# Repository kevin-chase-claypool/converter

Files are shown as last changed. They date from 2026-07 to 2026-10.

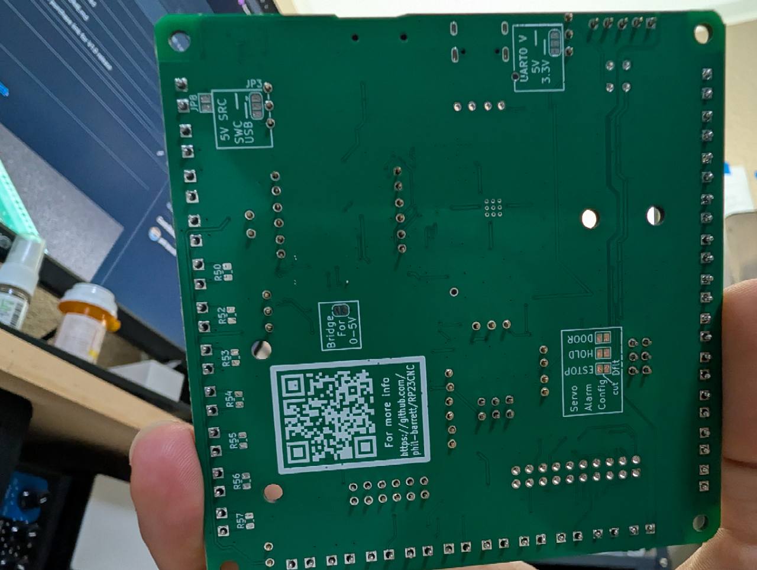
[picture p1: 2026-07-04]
docs/report/lab-notes/assets/2026-06-09-rp23u5xbb-v1.01-back.jpg

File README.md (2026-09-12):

# Theta Pen Plotter — System Integration Project

A polar (XY + rotating-bed) pen-plotting system. SVG artwork is converted on a
host PC into G-code for a machine whose **bed rotates under an XY gantry**, with a
force-controlled pen. This repository is split into independent components so each
can be edited and iterated on its own.

## Components

| Folder | What it is | Language / target |
|---|---|---|
| [`software/`](software/) | Host desktop app: SVG → G-code converter with a live Qt/OpenGL preview | Python 3 + PySide6 |
| [`firmware/`](firmware/) | Machine controller (motion via grblHAL) + the pen-pressure control system | grblHAL on RP23CNC; SparkFun Pro Micro RP2350 on the toolhead |
| [`docs/`](docs/) | Design/handoff notes and the System Integration in Robotics report | Markdown |
| [`samples/`](samples/) | Example SVG inputs and generated G-code outputs | assets |

New contributors and AI sessions should begin with
[`docs/START_HERE.md`](docs/START_HERE.md). It links the hardware inventory,
engineering log, master wiring table, architecture, interface contracts,
roadmap, test plan, and the categorized
[`change index`](docs/changes/INDEX.md).

For architecture, dependency, impact, or cross-subsystem investigations using
the local Ontoly graph, begin with the reusable
[`ONTOLY_PROMPT.md`](ONTOLY_PROMPT.md). It pairs graph evidence with the
authoritative interface, wiring, and commissioning records.

For a quick status view, open
[`project_management_overview.html`](project_management_overview.html) from the
repository root. It summarizes the active phase, current blockers, next work,
and links back to the controlling project documents.

## Run the converter

Double-click **`converter.bat`** (launches the Qt/OpenGL app and logs to
`software/qt_debug.log`), or:

```powershell
python software\qt_svg_to_gcode.pyw
```

See [`software/README.md`](software/README.md) for full usage and settings.

## System overview

```
   SVG  ──►  software/ (host)  ──►  .gcode  ──►  ioSender  ──►  RP23CNC + grblHAL  ──►  machine
                                                              │
                                                              └─ M3/M5 tool output ──►  pen-pressure MCU
```

- The host converter maps SVG artwork (bed-local coordinates) into machine
  `X/Y/A` moves for the rotating bed, and emits pen up/down as `M3`/`M5`.
- ioSender is the operator-facing G-code sender: it streams the saved G-code to
  RP23CNC over USB or Ethernet and provides the console, settings, jog, and
  status interface during setup and operation.
- grblHAL on RP23CNC parses the streamed G-code and drives the X/Y/A steppers.
- The pen-pressure system is an independent closed loop that treats the grblHAL
  `M3`/`M5` spindle/tool output state as a **mode override** (engage / lift) and
  otherwise holds a target contact force.

Use [`docs/README.md`](docs/README.md) to find the current architecture,
interfaces, tests, and open work. [`docs/HANDOFF.md`](docs/HANDOFF.md) retains
converter history and technical tradeoffs.

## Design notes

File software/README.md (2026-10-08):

# Host software — SVG → G-code converter

Converts `.svg` artwork into `.gcode` for the XY + rotating-bed (theta) machine,
with a live preview of the simulated machine motion.

- `qt_svg_to_gcode.pyw` — the primary app: PySide6 + OpenGL preview, playback,
  and all conversion settings in one window.
- `converter_core/` — the conversion engine split by responsibility:
  settings, SVG geometry, kinematics/planning, and G-code/preview move emission.
- `svg_to_gcode.pyw` — a compatibility shim for older imports and simple
  `input.svg output.gcode` command-line conversion.
- `qt_kaleidoscope.pyw` — the sibling app: imports an SVG, PNG or JPG, mirrors
  it into N kaleidoscope divisions, and saves the same G-code contract.
  Launched by `..\kaleidoscope.bat`; it reuses `converter_core/` unchanged.
  Its second tab, **Maps**, embeds a local copy of `piebro/plotting-maps` for
  turning OpenStreetMap exports into plotter SVGs.

## Run

```powershell
python qt_svg_to_gcode.pyw
```

or double-click `..\converter.bat` from the repo root. Runtime errors are written
to `qt_debug.log` in this folder.

Requires `PySide6` (`pip install PySide6`). The kaleidoscope's **Maps** tab
also needs Qt WebEngine, which ships in the full `PySide6` wheel
(`PySide6-Addons`); without it the tab reports the missing module instead of
failing the app.

The first two lines of `qt_debug.log` (and of the window's log pane) name the
converter core and the active A-axis guard, e.g.
`[A guard: park above 10 deg/segment, 20000 motor deg/min, travel rotations fed]`.
A window opened before a core change keeps the old planner in memory, so that
line is how a stale instance is told from a current one.

To check a *saved* file instead of the running app:

```powershell
python ..\tools\check_gcode_motion.py ..\samples\gcode\my-job.gcode --strict
```

It reports the largest bed rotation inside one drawing move, the largest A rate
demanded, whether any pen-up move carries rotation as a bare `G0` rapid, and the
worst commanded bed-path bow with its radius - measured from the file, so it
answers "did this program get the guard?" without guessing.

Two repeatability programs exist for measuring the machine itself, both safe to
Cycle Start with the pen loaded:

- `..\samples\gcode\a-repeatability-test.gcode` - the bed: a radial tick, two
  bed revolutions out and two back with the pen down, the tick again, at
  r = 100 mm and r = 160 mm. Ticks on top of each other means the bed returned.
- `..\samples\gcode\y-repeatability-test.gcode` - the heavy gantry axis: a tick
  across the axis, five runs out and back at 3000 / 6000 / 12000 / 20000 mm/min
  with the pen up, the tick again per rung. The top rung is what a `G0` pen-up
  travel actually runs at, because grblHAL ignores the `F` word on a rapid.
  Regenerate either with the matching tool in `..\tools\`
  (`make_a_repeatability_test.py`, `make_xy_repeatability_test.py --axis X`).

## Generator tabs

The window has the standard **File / Tools / View / Help** menu bar. **File**
opens the artwork (Ctrl+O), sets the G-code destination (Ctrl+Shift+S), saves
G-code (Ctrl+S), and exits. **Tools** is the tool selector: **All Tools**
(Ctrl+T) opens the card dashboard (Core, Line art, 3D, Patterns, Text &
layout), **Convert** is Ctrl+1, and the other tools follow in menu order with
Ctrl+2...Ctrl+0. **View** toggles the machine reach guide, pen-down path, and
log, and controls preview zoom. The preview panel also has a **Red motion
lines** checkbox next to Fill bed / Fit inside that toggles the same pen-down
overlay without leaving the preview (it stays in sync with the sidebar
checkbox and the View menu), plus an **Ink simulation (multiply)** checkbox
for CMYK previews: the ink layers multiply over the paper white in plot
order, like translucent pens, so the preview shows the finished overprint
instead of painting each layer opaquely. Simulation strokes draw at the real
pen width, and a stroke thinner than a screen pixel fades toward white by the
fraction of a pixel it covers, so the fit-to-window view keeps the density
the paper will get (zoom in for full-strength strokes). Mixing only happens
where strokes overlap: keep the effective pitch (Dot pitch x Artwork scale,
then the tone-adaptive factor of 1-3x) at or below the pen width for full
coverage. An **Ink profile...** button loads
the `*-profile.json` written by `tools\cmyk_calibrate.py`, so the simulation
multiplies your pens' measured transmittances instead of the display ink
colours. **Help** has the shortcut list
(F1) and About.
The status bar shows the current artwork and G-code paths. Tools are
contributed by `software/generator_tabs/*_tab.py` modules and discovered at
startup, one page per tool; a broken tool is reported in the log instead of
stopping the app.

Import, **Preview / Cancel / Save G-code**, and the OpenGL preview panel are
static window furniture: they stay visible on every tab. Pressing **Preview**
builds the active tab - Convert previews the Artwork row's file, while Flow
Field, Line Draw, and 3D Wireframe build their own SVG from their controls -
and that result runs through the same converter pipeline into the shared
preview panel. **Save G-code** exports the active tab's result. Switching tabs
never rebuilds anything; it marks the visible preview as belonging to another
tab until Preview is pressed again. Multi-layer tools (CMYK) keep that static
Preview for the overlaid view; after a successful preview the four per-ink
programs plan in the background and **Save 4 G-code files** writes them
through one save dialog owned by the window.

Tool authors: the contract and the host entry points are documented in
[`generator_tabs/README.md`](generator_tabs/README.md). Ported or vendored
third-party code keeps its license and attribution in a sibling
`<name>_NOTICE.md`.

Current tools:

**Photo-based** (need an image from File > Open Artwork):

- **Line Draw** - raster image to edge-traced contours plus luminance hatch.
  Controls: artwork (from the static Artwork row), invert, mode
  (contours / hatch / both), edge
  threshold, hatch spacing, hatch light/mid/dark thresholds (upstream
  linedraw levels 144/64/16), sketch jitter, minimum length, simplify,
  resolution, line width, seed, page size, margin, artwork scale.
- **CMYK** - RGB to CMYK separation with gray-component replacement, screened
  as one layer per ink pen. Controls: artwork (from the static Artwork row),
  an **Auto (photo)** button that analyzes the image and sets auto levels,
  brightness, contrast, saturation, GCR, a starting gamma and the dot pitch
  (tone
  controls come from a detail search over the real curve chain: maximum mid
  tone-weighted gradient with a clipping penalty, so structure stays
  legible instead of crushed or blown, and the search also holds the print's
  mean tone on the photo's, clamped to the 0.30-0.75 window a plot can
  actually hold, so portraits are not lifted a stop too light; it also
  renders the rectilinear screen (Pen width and Dot pitch x Artwork scale)
  before choosing, so a row pitch at the pen width - which inks only about a
  fifth of a light tone - gets a darker chain instead of a washed-out plot,
  while a screen finer than the pen gets a lighter one; saturation
  and GCR come from the
  image's colourful quartile, so a vivid subject over neutral ground keeps
  its chroma; the pitch is set to one pen width at the current artwork scale,
  the same as **Match pen**),
  auto levels (default on: stretch the image's 1st-99th luminance percentiles
  so low-key photos use the full tonal range), saturation, contrast,
  brightness, ink gamma, black (GCR), resolution, per-ink weights, screen style
  (halftone dots / stipple dots / line screen / crosshatch levels / wave
  screen / interference (gyroid) / single line (TSP) / topographic contours /
  rectilinear fill),
  dot pitch (with a **Match pen** button that sets it to one pen width at
  the current artwork scale), dot size, solid dots (spiral-filled so each
  mark reads as a dot, not a ring), hatch levels, overdraw, pen width, max
  marks per ink, seed, preview and write checkboxes per layer, page size,
  margin, artwork scale, and registration corner crosses (all four inks
  draw the same four margin crosses so pass alignment can be checked).
  Resolution keeps the source image's longest side up to that many pixels
  and never upsamples, so it accepts high-resolution sources (the control is
  effectively uncapped; memory grows with the source size you keep).
  Shipped defaults are the owner's tuned rectilinear set: auto levels on,
  rectilinear fill at 0.10 mm pitch (its light-tone stretch opens the pitch
  up to 7x, so highlights and mid tones keep paper while dark tones fuse
  solid, and the pitch follows the tone the row actually inks and eases
  between rows so it does not step where the subject meets the background),
  saturation 115 %, contrast 285 % (the soft S-curve keeps
  steepening up to 300 % instead of clipping), brightness 170 %
  (shadow-weighted lift), ink gamma 1.40 (about a third less ink in the mid
  tones), black (GCR)
  95 %, hatch levels 8, artwork scale 280 %, dot size 100 % with solid dots
  off (both only affect the dot screens), 40000 marks per ink, 10000 px
  resolution, C/M/Y/K weights 100/100/100/100 %. The preview checkboxes decide which inks the shared OpenGL preview
  draws, and they apply instantly: every layer stays loaded, so toggling a
  checkbox never re-screens or re-plans. For CMYK previews the preview data
  area also reports the per-ink M3 (pen-down) counts as
  `C: n M: n Y: n K: n`, counted from the planned program.
  Pressing Preview also plans each checked ink's own program in the
  background through the same pipeline as Convert - that planning is exactly
  where the r-theta solver picks x_theta or y_theta per segment, and the tab
  reports each file's split and calibrated time when it finishes.
  **Save 4 G-code files** writes
  `<name>-cyan.gcode`, `-magenta`, `-yellow` and `-black` from one base name.
  The r-theta axis-cost solver and the M3/M5 pen contract are inherited
  unchanged, so each ink is as cost-efficient as a normal Convert program.
  Line, wave, gyroid, TSP and contour styles are the fast continuous-mark
  alternatives to dot styles: they draw far fewer pen-lift cycles, while the
  overdraw control darkens any style by redrawing each mark up to three times
  with a sub-pen offset.
  While the CMYK page is active the shared OpenGL preview draws each visible
  ink in its own colour - not yet drawn marks in a pale tint, the drawn path in
  full ink - so the four layers can be judged overlaid the way they will mesh
  on paper. The red machine-motion overlay and every other tool keep their
  existing single-colour preview.
  **Test sheet** (Calibration group) replaces Preview and Save with a
  calibration page instead of the artwork: per-ink coverage and overdraw
  ladders, a dot-size, line-pitch, or hatch-level ladder, a GCR ramp,
  dense full-tone mixes (pairs, triple, and the C+M+Y+K quad) and single-ink
  spots at the same tight spacing, blank paper, and four corner fiducials;
  the only printed text is a two-line identification header
  (page, margin, screen), because the cell values live in the manifest. The
  **Sheet screen** box defaults to matching your Screen style (line screen
  and crosshatch included), so the ladders calibrate the marks you actually
  print; line sheets draw continuous strokes and need far fewer pen cycles
  than dot screens. Save writes `<name>-calibration-*.gcode` plus
  `<name>-calibration.json`; plot the four files in C, M, Y, K order, scan
  the sheet flat, and run
  `python tools\cmyk_calibrate.py scan.png --manifest <name>-calibration.json`
  to report paper-relative ink transmittances and a multiply-model check for a
  print-matching preview. Ladder cells print raw tone; raise the pitch for a
  faster calibration plot. The full print-scan-analyze handoff (including
  analyzing a scan with no manifest) is
  [`../docs/testing/CMYK_CALIBRATION.md`](../docs/testing/CMYK_CALIBRATION.md).
- **SquiggleCam** - one continuous squiggle per row from image tone (full
  upstream setting set): line count, frequency, amplitude, brightness,
  contrast, min/max brightness, pixel spacing, resolution, black-background
  inversion, page, line width, artwork scale.
- **Pixel Art** - pixel-art paths in `big` (5x5 spiral), `line` (runs), or
  `snake` (connected) mode, from vpype-pixelart: pixel pitch, overdraw, max
  grid, alpha threshold, ignore-white, page, line width, artwork scale.
- **Plotterfun** - the complete upstream `mitxela/plotterfun` web app (22
  algorithms) vendored under `software/plotterfun_vendor/` and embedded with
  QtWebEngine. Load the image and choose the algorithm inside the page, then
  press **Export SVG to plot**; requires PySide6-Addons.
- **Layers** - splits the imported SVG by stroke/fill colour into per-layer
  SVGs; pick a layer to preview and plot one pen at a time. The source SVG's
  own dimensions are preserved.
- **Stipple / TSP** - density stippling with weighted Lloyd relaxation and
  route-optimized TSP art. Controls: invert, density gamma, points, Lloyd
  passes, seed, style (dots / TSP line / both), dot size, 2-opt passes, page
  size, margin, line width, artwork scale.
- **Vector Trace** - clean outline tracing for logos and silhouettes.
  Controls: Otsu/manual threshold, trace-light-regions, simplify, smoothing,
  minimum area, fill (outlines / hatch / both), hatch spacing and angle, page
  size, margin, line width, artwork scale.

**Algorithm only** (generate from parameters; optional files noted):

- **Flow Field** - evenly spaced streamlines from a procedural noise field, an
  image's luminance gradient, or a user formula (angle f(x,y) or vector dx/dy,
  with presets). Controls: source, preset, formula mode, formulas, artwork
  (from File > Open Artwork), invert, image cutoff, seed, noise scale,
  octaves, spacing, step, max steps, line width, page size, margin, artwork
  scale. Optional image-edge source; works standalone on noise or formulas.
- **3D Wireframe** - OBJ or STL mesh to orthographic hidden-line vector art.
  Built-in primitives (cube, sphere, cylinder, cone, terrain plane) and a
  perspective camera. Controls: source, file/primitive, style
  (hidden-line wireframe / silhouette / all edges), yaw, pitch, roll,
  projection, camera distance, target width, sample step, page size, margin,
  line width, artwork scale. Works from the built-in primitives; a mesh file
  is optional.
- **Harmonograph** - damped Lissajous figures from two decaying oscillations,
  or the upstream physical two-pendulum + rotating-disk model. Controls:
  model, pivot/arm geometry, rotating-disk frequency, amplitudes, phases,
  per-axis damping, frequencies, duration, samples, smoothing, page size,
  margin, line width, artwork scale; the simple model keeps seed, frequency
  X/Y, phase, damping, turns, samples, and curve count.
- **Snowflake** - radial dendritic snowflakes with jittered branches.
  Controls: seed, arms, branch depth, arm length, branch angle, branch scale,
  angle jitter, length jitter, page size, margin, line width, artwork scale.
- **Truchet** - Truchet tiles as quarter arcs, diagonals, or mixed. Controls:
  seed, tile size, style, arc segments, page size, margin, line width,
  artwork scale.
- **Text** - monoline single-stroke text using the vendored public-domain
  Hershey simplex font. Controls: text lines, text size, tracking, line
  spacing, alignment, page size, margin, line width, artwork scale.
- **Substitution** - 2x2 colour-substitution pattern from a seeded palette,
  drawn as colour boundaries or one diagonal per cell. Controls: seed,
  colours, iterations, style, page size, margin, line width, artwork scale.
- **Postcard** - plottable postcard back: border, centre divider, stamp box,
  address guide lines, and optional caption/message/address text. Controls:
  page preset (default upstream 7x5 in landscape), divider, address lines,
  line spacing, stamp size, caption, message, address, text size, tracking,
  page size, margin, line width, artwork scale.
- **Wobble** - hand-drawn wobble applied to the current preview contours
  (line-wobbler): frequency, amplitude, frequency jitter, seed, endpoint
  wobble toggles, margin, line width, artwork scale. Runs on the current
  preview contours, so preview another tool first.
- **Voronoi** - bounded Voronoi cells with optional Lloyd relaxation.
  Controls: points, seed, relaxation, style (cell boundaries / site dots /
  both), dot size, page size, margin, line width, artwork scale.
- **Path Prep** - vpype-style cleanup of the current preview contours:
  linemerge, deduplicate, reloop, and linesort. Controls: merge angle and
  tolerance, duplicate tolerance, gap closing, sort/reverse, 2-opt passes,
  margin, line width, artwork scale. Preview another tool first.
- **Reaction-Diffusion** - Gray-Scott patterns extracted as contour lines.
  Controls: grid, steps, feed/kill, diffusion A/B, seeds and seed size, seed,
  contour level and level count, page size, margin, line width, artwork
  scale.

Image-driven tabs read the file already loaded in the static Artwork row
instead of repeating the import control.
Every generator tab has an **Artwork scale** control (10-1000%) that scales its
result about the page centre.
The Text tab (and the Postcard tab's caption/address) uses the vendored
public-domain Hershey simplex font in `generator_tabs/fonts/`; its use terms
are in `generator_tabs/fonts/NOTICE.md`.
Generator pages are previewed **1:1** with the auto fit skipped, so that
Artwork scale sets the physical drawing size; imported artwork on the Convert
tab still uses the selected Fit mode.
Generator tab controls fill the settings column, with the tab's hint and
status text stacked below them; the settings column has a 280 px floor so it
cannot be crushed by the preview.

The menu bar, status bar, **Preview** and **Cancel** buttons in the preview
panel, and the OpenGL preview itself (status, estimate, progress, fit/clip
controls) are window furniture outside the tool pages, so they stay visible
whichever tool is active. The preview fills the whole area to the right of the
feature settings pane; only the settings sidebar belongs to the Convert page.

### Recommended starting settings

These defaults are tuned for a 200 x 200 mm page, a 0.3 mm pen, and the 1:1
preview. They also appear in the app under **Help > Recommended Settings**.
Photo-based tools need an image via File > Open Artwork; algorithm-only tools
work with no input (optional mesh/image sources are noted below).

| Tool | Start from | Notes |
|---|---|---|
| Convert | Fit bed (auto), Fill spacing 3 mm, linear or crosshatch, feed 700 / travel 3000 mm/min | Imported artwork; Save G-code once the preview looks right. |
| Flow Field | Noise source, scale 60 mm, octaves 3, spacing 3 mm, step 1 mm, 400 steps | Spacing 3 mm is dense; use 4 mm for a first plot. |
| Line Draw | Both modes, edge 35 %, hatch 2 mm, levels 144/64/16, jitter 0.25 mm, simplify 0.75 px, resolution 900 px | Needs an image in the Artwork row. |
| CMYK | Auto levels on, rectilinear fill at 0.10 mm pitch, saturation 115 %, contrast 285 %, brightness 170 %, ink gamma 1.40, black (GCR) 95 %, 40000 marks/ink, resolution 10000 px, weights 100/100/100/100 %, artwork scale 280 % | Needs an image; Preview plans each ink in the background and Save writes four files. Dense photo screens take hours to plot; raise pitch or lower Max marks/ink for a faster pass. |
| 3D Wireframe | Cube, size 2, detail 24, hidden-line wireframe, yaw 35 / pitch -25, perspective 4x radius, target width 140 mm, sample 0.7 mm | Works with no file; switch Source to File for OBJ/STL. |
| Harmonograph | Physical model: d 900 / c 800 / p 900 / q 700 mm, A 10 / B 10 deg, R 0.001 / S 0.001, f 0.300 / g 0.302 Hz, disk 0.0008 Hz, 300 s, 12k samples | Upstream defaults; the simple model is a lighter alternative. |
| Snowflake | 6 arms, depth 3, length 45 %, branch angle 35 deg, branch scale 55 %, jitter 8 deg / 15 % | Raise depth for finer detail; cap is 5. |
| Truchet | Quarter arcs, tile 12 mm, 10 arc segments, margin 6 mm | Diagonal and mixed styles use the same grid. |
| Text | Size 12 mm, tracking 0.4 mm, line spacing 140 %, alignment left | Uses the bundled Hershey simplex font. |
| Substitution | 3 colours, 4 iterations (32 x 32), colour boundaries, margin 6 mm | Each extra iteration quadruples the path count. |
| Postcard | 7x5 in landscape, margin 8 mm, line spacing 9 mm, stamp 25 x 30 mm, text 6 mm, tracking 0.2 mm | Matches the upstream default page. |
| SquiggleCam | 50 rows, frequency 150, amplitude 1.0, spacing 4 px, resolution 700 px, brightness 0, contrast 0, min 0 / max 255 | Needs an image; lower frequency raises the wiggle. |
| Pixel Art | Mode big, pitch 0.6 mm, max grid 96, alpha 128, ignore white | Paths auto-fit the page; big mode needs 5x the pitch per pixel, line mode is denser. |
| Wobble | Frequency 3 mm, amplitude 0.5 mm, jitter 20 %, seed 7, endpoint wobble on | Preview a tool first; Wobble processes those contours. |
| Plotterfun | Load an image inside the page, pick an algorithm, keep its defaults, then Export SVG to plot | Requires QtWebEngine (PySide6-Addons). |
| Voronoi | 120 points, seed 7, relax 1, cell boundaries, margin 6 mm | Raise relax for even cells; site dots show the seeds. |
| Path Prep | Merge 5 deg / 0.05 mm, duplicate 0.05 mm, close gaps 0.2 mm, sort on | Preview a tool first; cleans those contours. |
| Layers | Pick a colour layer (or All colours) from an imported SVG | One layer per pen; the source dimensions are kept. |
| Stipple / TSP | 600 points, 3 Lloyd passes, gamma 1.0, dots + TSP, dot 0.6 mm, 5 2-opt passes | TSP mode gives one continuous line; raise 2-opt passes for shorter travel. |
| Reaction-Diffusion | Grid 128, 4000 steps, f 0.037, k 0.060, Da 0.16, Db 0.08, one seed of 8, level 0.20 | Raise steps for finer detail; grid 128 keeps the build quick. |
| Vector Trace | Otsu, simplify 1 px, smoothing 1, min area 6 px2, outlines | Add hatch at 1.5 mm / 45 deg for filled shapes. |

## Kaleidoscope Converter

`qt_kaleidoscope.pyw` (or `..\kaleidoscope.bat`) builds an N-fold mirrored
design from an SVG, PNG or JPG and emits the same program contract as the main
app.

- **Same planner, same A-axis guard.** This window has no kinematics of its
  own: `output_settings()` starts from `converter.Settings()` and the program is
  produced by `plan_program` + `contours_to_gcode`, so it inherits every
  converter rule including the bed-parking guard (no segment rotating the bed
  more than 15 deg) and the 20000 motor deg/min assumed A limit. It therefore
  needs a **restart** after a converter-core change, exactly like the main app;
  the startup log names the loaded build (`Converter core <version>: A-axis
  guard active ...`) and the same line goes to `kaleidoscope_debug.log`.
- **Control column.** Every group is open at once, so the column of controls is
  taller than a laptop window. It lives in a scroll area - scroll it down to
  reach `Build preview` and `Save G-code...`. The sidebar is never narrower than
  the widest row needs, so the vertical bar is the only one that appears and no
  label or spin box is cut off.
- **Source.** SVG geometry goes through the same parser, fill and clipping as
  the main app. A raster image is traced by marching squares into closed
  contours (`converter_core.kaleidoscope.trace_raster`), so a traced region can
  also be filled by the normal fill settings; `Image threshold`,
  `Treat light pixels as ink` and `Trace detail` control that trace.
- **Random pattern.** Tick `Generate a random pattern instead of artwork` to
  draw the source with the built-in generator instead of importing one. `Seed`
  (with `New seed`) selects a design and `Intricacy` (1-10) deepens every layer;
  the amount of drawing only ever grows with it. The pattern is composed in the
  current wedge the way an engraved mandala is drawn - a layered centre (nested
  rosette, ray spokes, bead rows), then shape rings of shaded leaves, tulips,
  lenses, topographic bundles, feathers, scallops, chevrons, rayed fans, diamond
  mesh, lace scales and bead rows, with separator bundles, stud flowers and dot
  rows between them, closed by a scalloped multi-line rim. Detail counts are
  driven by physical spacing - contour fills, studs, dots, barbs and hatch lines
  are placed one every few millimetres along the arc - so the design gets
  complicated the way an engraving does rather than by repeating one texture.
  The bead rows, stud flowers and dotted rings are ornaments rather than
  structure, so they have their own spacing: `Ornament spacing` (1.0-8.0,
  default 2.0) is how far apart they sit as a multiple of the engraved
  hatching's pitch. 1.0 packs them edge to edge and reads as printed wallpaper,
  2.0 is the sparse default, and 4.0 or more leaves a few ornaments per band.
  That is the control for how wallpaper-like a design looks; the shaded
  leaves, lenses, separators and rim arcs keep their own spacing. It maps to
  `random_pattern(ornament_pitch=...)`, whose default is
  `generative.ORNAMENT_PITCH`.
  The result is clipped, mirrored, offset, auto-fitted and saved exactly like an
  imported image, so one seed plus the other controls reproduces the same
  G-code. The seed changes the *structure*, not just the phases: it picks one of
  five composition styles (`floral`, `geometric`, `woven`, `beaded`, `mixed`),
  the ring count, the band-width ladder, how much of the disc the centre and rim
  take, how tightly each layer packs, and whether a shape repeats once or twice
  per wedge - the style name is shown next to the seed. Counts, radii and phases
  come from mathematical sequences (golden angle, Weyl, van der Corput,
  Fibonacci, primes), not from unseeded noise.
  Drawn shapes are hatched the way an engraved botanical plate is: a leaf is an
  irregular outline with nested contour lines, radial ribs every few
  millimetres and a centre vein, so the pattern reads as hand-drawn line work
  instead of empty mechanical rings.
  `Region overlay` sets how much neighbouring radial regions share: 0 tiles the
  rings edge to edge, 0.2 (the default) braids them slightly, 0.5 and up
  interpenetrate heavily. The bands grow as they overlap so the disc stays
  covered and no shape is stretched - each ring simply draws a larger version
  of itself. This is the knob for making a design look denser and more complex
  without adding more rings.
- **Natural motifs.** `Motif folder...` loads a folder of black-on-white
  PNG/JPG shapes - leaves, shells, fish, feathers - and `Use natural motifs in
  patterns` swaps them in for the drawn shape rings while the separators, studs
  and rim stay. Each ring draws from a pool of one to three motifs, so the seed
  *combines* natural shapes around the ring rather than repeating one; a share
  of the copies overlays a smaller second motif to form a hybrid, alternating
  copies can be mirrored, and every copy is deliberately larger than its band
  and drifts in and out of it so the shapes overlap their neighbours. The ring
  count drops in this mode so the motifs stay large enough to recognise. The
  `Image threshold`, `Treat light pixels as ink` and `Trace detail` settings
  apply to the motifs too (use invert for white-on-black artwork); traced
  motifs are cached until the file or those settings change, and only the
  motifs the current seed will place are traced. `Seed` decides which motifs,
  how many copies, their orientation, tilt, mirroring and packing.
  Two sets ship ready to use (see `..\motifs\README.md`): `..\motifs\nature`
  holds 150 real organism silhouettes from PhyloPic - birds, cats, elephants,
  fish, dolphins, insects, jellyfish, plants - with per-file credits, and
  `..\motifs\nature-drawn` holds the earlier code-drawn set.
  `..\tools\fetch_phylopic_motifs.py` fetches more organisms,
  `..\tools\make_nature_motifs.py` redraws the drawn set, and
  `..\tools\fetch_nature_motifs.py` pulls free silhouettes from Wikimedia
  Commons. In motif mode each shape is drawn with two smaller nested copies
  inside it, so real outlines read as engraving rather than as flat cut-outs.
  Intricacy 10 is a full engraving: in a 12-division 181.3 mm frame it draws
  about 13,500 mirrored contours and 310,000 points, roughly 390,000 G-code
  lines and 13,500 pen cycles; the build takes about a second and saving the
  program about twenty. Lower levels are proportionally lighter. The
  artwork-only controls (open button, threshold, invert, trace detail) are
  disabled while this mode is on.
- **Kaleidoscope.** The source is centred on the apex and clipped to a
  half-wedge of `180 / Divisions` degrees, then placed `2 * Divisions` times
  around the circle, alternating mirrored copies so 360 degrees tile exactly.
  With `Mirror alternate sectors` off the wedge repeats without reflection,
  which gives a pinwheel instead of mirror symmetry. `Rotate source` chooses
  which slice the wedge samples.
- **Image placement.** `Image offset X/Y` moves the source inside the fixed
  frame, in millimetres of the finished design, and the same values can be set
  by dragging in the preview: the wedge, the design bounds and the machine
  limits stay where they are and only the image moves. Content pushed outside
  the frame is clipped, so a drag can empty the wedge — the preview and log show
  that immediately.
- **Printable bounds.** `Bed diameter`, `Bed margin` and `Gantry reach radius`
  are typed values that feed both the preview and the planner, with the
  resulting `Bed allows … / reach allows …` shown underneath. `Fit radius` is
  the radius the design is fitted to and clipped at; `Fit design to bounds`
  scales `Source size` so the design's natural radius matches it, and
  `Auto-fit after a division or rotation change` keeps it matched while the
  design changes. The default 181.3 mm is 0.98 x the 185 mm reach, and the
  planner still clips the saved program at the real printable limit if a typed
  bound is larger. `Source size` and every bound field are free numbers: the
  old 400 mm source cap and 300 mm bound caps were arbitrary guards, and the
  spin boxes now accept up to 1,000,000 mm (the fit radius is what actually
  keeps the plot on the bed). Auto-fit only ever rewrites `Source size`, so a
  huge source is scaled down to the fit radius before it is clipped and planned.
  Typed numbers are never rewritten by auto-fit: changing the seed, the
  intricacy, the divisions or the fit radius scales the drawing internally
  (the scale is printed in the log and the bounds note) and leaves every field
  exactly as entered. `Fit design to bounds` is the one button that writes a
  fitted value into `Source size`.
- **Output.** `Tolerance`, `Fill spacing`, `Feed rate` and
  `Theta tangential speed` are the same settings as the main app, and the saved
  file uses the same preamble, pen contract, clipping and end-of-print park.
  Fill spacing stays `0` (outlines only) by default.
  `Pen tip diameter` records the physical tip - the machine's Sakura Pigma
  Micron 005 is 0.20 mm, which is also the default. It sets the pen-width
  compensation applied to imported SVG artwork (the artwork is shrunk by one
  tip width so the outside of the stroke lands on the intended outline), the
  gap fill bridging tolerates, and is written into the saved program's header.
  Generated patterns and traced images are not compensated.
  `Tolerance` is the accuracy budget: the emitter subdivides each draw move so
  the commanded path stays within that many millimetres of the intended line on
  the bed. It binds hardest where the bed rotates most per millimetre - tight
  curves near the centre and long sweeping arcs - so a coarse value shows up as
  wobble in the middle of a mandala, and **on a coarse value the rows themselves
  are commanded to drift into their neighbours**: measured with
  `tools\check_gcode_motion.py`, programs saved at `Tolerance 1.0` carried bows
  of 1.2-1.9 mm against a 2 mm row pitch (62-95 % of a pitch), while 0.15 bounds
  it to 0.15 mm (7 %) for about 0.15 % more moves. Keep it at 0.1-0.15 unless a
  source is so detailed that the extra points cost too much. Saving a program logs the worst deviation
  the file actually contains and where it sits; on a 212k-move mandala, going
  from 1.0 mm to 0.1 mm costs about 0.1 % more moves and cuts the worst
  deviation from 0.9 mm to 0.1 mm.
- **Remembered setup.** The app saves its settings to
  `kaleidoscope_settings.json` next to the script (git-ignored) whenever it
  closes and whenever a motif folder is chosen: the motif folder, source path,
  seed, intricacy, divisions, mirror, rotation, source size, image offsets,
  threshold, trace detail, every printable bound, tolerance, fill spacing, feed
  rates and the mode checkboxes all come back on the next launch. On a first
  run with no settings file, the motif folder defaults to `samples\png` if that
  folder exists (otherwise `motifs\nature`) and both **Use natural motifs in
  patterns** and **Generate a random pattern** are ticked, so the app opens on
  a pattern built from those images. A file that would trace into more than 200
  contours or 4,000 points is skipped with a log line - that means it is a
  whole drawing rather than a single shape, and the affected ring falls back to
  the drawn families.
- **Motifs in use.** `Motifs in use` caps how many images from the folder a
  design may draw on, and it defaults to **10**: the app picks that many at
  random from the folder - `New selection` draws a different random set - and
  only those are traced, offered to the generator and cached. A folder of 150
  organisms therefore costs about ten traces instead of the whole set, which is
  what keeps the launcher from grinding through every PNG. Raise the number if
  you want a wider palette, lower it for a tighter look; the choice, the
  selection and the folder all come back on the next launch.
- **Preview view.** The preview is a flat bed-frame view — bed circle, reach
  circle, the sampled wedge and the design — with the same camera gestures as
  the main app: the wheel zooms about the cursor (10 % to 2000 %), `Shift`-drag
  or middle/right-drag pans, and the `+` / `-` / `Reset view` buttons with
  `Ctrl` `+` / `-` / `0` do the same from the keyboard. A plain drag still
  moves the image inside the fixed frame, and that drag is scaled by the zoom,
  so it stays accurate when you are zoomed in. The current zoom is shown next
  to the buttons and in the preview's status line. There is no OpenGL playback;
  use the main app when you want the simulated machine motion.

### Maps tab

The window opens on the **Kaleidoscope** tab and also carries a **Maps** tab: a
vendored, offline copy of
[`piebro/plotting-maps`](https://github.com/piebro/plotting-maps) (MIT), which
turns an OpenStreetMap export into a plotter SVG.

- **A separate plotting function, not a mode.** The tab owns its controls and
  its output. `Download Map` opens a normal save dialog and writes an ordinary
  SVG; nothing there changes the kaleidoscope source, design, settings or
  G-code, and nothing from the kaleidoscope feeds the map.
- **Offline by construction.** `plotting_maps/` holds the page with its own
  `d3` and `proj4` copies and no analytics, so the tab never reaches the
  network. See `plotting_maps/README.md` for the pinned upstream commit, the
  local modifications and the licence notes.
- **How to use it.** On openstreetmap.org use *Export → Manually select a
  different area → Overpass API* to download an `.osm`, then **Upload OSM
  Export** in the tab, set the paper size, zoom and drag the map into place,
  and **Download Map**. The saved SVG is an ordinary vector file that can be
  loaded into either app or any other tool.
- **Lazy start.** The web view is created the first time the tab is opened, so
  the kaleidoscope starts as quickly as before and an environment without
  WebEngine can still plot.

## What it emits

- `G21` (mm), `G90` (absolute), `G94` (units/minute feed), `G17` (XY plane),
  and `G54` (the registered work-coordinate frame)
- a header comment recording the bed ratio, theta offset, feeds, tolerance and
  the A-axis limits the planner assumed (`(A limits assumed 15000 motor
  deg/min, 3000 motor deg/s^2)`), so a program can always be traced back to its
  motion settings - compare that line with the controller's `$$` after any
  settings change, because a converter assumption above what the controller
  allows makes the emitted feeds unachievable and the time estimate optimistic
  (`tools\make_theta_calibration.py` writes a plot that measures the
  bed's real ratio: a circle plus a two-turn spiral, where a wrong ratio shows
  as an offset that doubles on the second lap)
- the bed is re-registered at every contour by default: the planner subtracts
  whole revolutions from the bed angles, which leaves every drawn point where it
  was but keeps the commanded `A` within about one turn instead of letting it
  wind up over the program. On a machine with a small A-axis scale error the
  positional error grows with the commanded angle, so this removes most of the
  drift seen at high `A` values. The main app exposes it as
  `Re-register the bed each contour (keep A small)`; turn it off to reproduce
  older programs. It bounds the symptom, not a mis-calibrated A axis - the
  calibration plot above is still how the true ratio gets measured.
- pen-up travel is emitted as **fed `G1` moves, never `G0`**. A rapid ignores the
  program's `F` word and runs at the controller's `$110`/`$111` maxima, so a
  travel would run at whatever rate the controller is configured for - on this
  machine 8000 mm/min = 133 mm/s on the Y axis that carries most of the mass -
  while the preview, the time estimate and `Travel rate` all assumed 3000. Fed
  travel makes the machine do what the file says: the long crossings and the
  end-of-program park now run at the modelled rate, which is also the slowest
  and safest the gantry ever moves. The cost is small - the whole of `ben.gcode`'s
  1777 mm of pen-up travel takes 44 s at the modelled rate against 42 s if every
  move ran at the 8000 ceiling - and a bed re-registration spin still runs at
  the A rate cap, which is why its `F` is larger than `Travel rate`: the feed is
  the coordinated rate over a path that counts A motor degrees as millimetres.
- `G1` draw moves (pen down)
- `X Y` in mm in the machine's active work-coordinate frame; `A` =
  **motor-shaft degrees** (already multiplied by `Theta ratio`)
- `M5` / `M3` pen up / down by default. `Z` moves are available only when
  **Use Z axis** is deliberately enabled; do not enable it for this machine,
  whose controller's Z slot is unwired. **Wait for GP27 toolhead ready** is on
  by default, so each M3/M5 transition is acknowledged with the
  RP23CNC-resident `G65 P115` bounded macro instead of a fixed `G4` dwell;
  uncheck it to go back to the dwells if the controller is missing the handshake
  prerequisites. Its companion **Lift pen and continue if the GP27 handshake
  times out** is also on by default and turns a timeout into a logged warning
  plus a pen lift instead of a mid-print abort.
- `M2` at end

The converter normalizes the clipped SVG around its geometric center before
planning. That center is emitted as `G54 X0 Y0`, matching the pen-at-bed-center
frame registered by P100 (or the narrowly scoped temporary commissioning
reference). After the final pen-up the program ends with a `G53 G0` move to a
configured machine-coordinate park position (defaults to the homed rest
position). First it asserts Aux0/GP28 (`M65 P0`) to request a full retract to
the toolhead's GP2 lift-home switch, waits for the clear-ready acknowledgement
(`G65 P115 Q0` when the handshake is enabled, otherwise the fixed `G4 P3.0`
retract dwell), and releases Aux0 (`M64 P0`), so the pen is fully up before the
gantry clears the rotating bed.

The authoritative host-to-controller contract is
[`../docs/integration/INTERFACES.md`](../docs/integration/INTERFACES.md).

## Radius-aware A-axis feed

The converter must not treat the A-axis portion of `F` as a fixed bed-surface
speed. Because `A` is emitted in motor-shaft degrees and the measured bed
reduction is 12.0332:1, the A rate required for a target tangential pen speed
pen's instantaneous radius from the bed center:

```text
A_feed_motor_deg/min = (4331.97 × tangential_speed_mm/min) / (2π × radius_mm)
```

`Feed rate` remains the requested maximum X/Y component speed. The additional
**Theta tangential speed mm/min** setting is the requested bed-surface speed
for draw segments that include A motion. For each segment, the converter uses
the average endpoint radius, limits the requested A rate using the installed
RP23CNC profile (`$113 = 80000` motor-deg/min and `$123 = 6000`
motor-deg/s²), and derives one coordinated `F` from the longer X/Y or A
component duration. X/Y-only output remains unchanged.

At the exact bed center, rotation has zero tangential effect. The converter
therefore uses the capped angular move required by the theta plan without
dividing by zero and reports zero achieved tangential speed. The acceleration
limit is a conservative rest-to-rest segment bound; grblHAL can carry speed
through adjacent blocks, so M-06 hardware validation is still required before
relying on estimated execution time at high speed.

Preview draw moves use this same planner and retain the resulting feed, radius,
achieved tangential speed, and limiting reason in their move data. Generated
G-code and preview blocks therefore agree. Unit tests cover inverse-radius
rates, forward/reverse motion, both A limits, center handling, unchanged
X/Y-only output, and preview/G-code parity.

## Settings groups (Qt app)

Each setting lives with the thing it changes. Only **Preview settings** is
display-only; every other group changes the emitted program.

- **Geometry** — scale, tolerance, artwork placement (see *Placing the
  artwork* below), Flip Y, pen-stroke compensation, and
  **Expand strokes to outlines** (off by default — a pen already marks its own
  width, so drawing each stroke's centerline once is correct and produces far
  fewer M3/M5 cycles than outlining the stroke width).
  **Fill wide strokes** (off by default) fills a stroke only when its width is
  at least **Stroke fill ratio** times the pen diameter: a stroke that wide is
  drawn as parallel passes spaced one pen diameter apart, while every thinner
  stroke stays a single centerline. This renders genuinely thick strokes solid
  without paying the outline penalty on thin ones.
  **Tolerance** also bounds how far a drawn move may bow from a straight
  bed-frame line: because the controller interpolates X/Y/A linearly across one
  move, a move that spans bed rotation is subdivided so each chord stays within
  tolerance of the intended path.
- **Fill** — everything about hatching the artwork: spacing (0 = outlines
  only), pattern, angle, `Fill source`, shade levels/angle step, the
  pattern-specific size fields, the image-tone sampling resolution, and
  **Keep pen down between fill trails** (off by default; it only ever joins
  generated fill trails, never the artwork's own strokes). See *Fill* below.
- **Motion** — draw/feed rate and travel rate. Values that cannot describe a
  meaningful X/Y/A program (for example, zero feed, a nonpositive theta ratio,
  an invalid A-axis name, or a bed margin that leaves no drawable area) are
  rejected before preview or save.
- **Machine** — the machine-side setup the program is clipped and parked
  against: `Bed dia mm`, `Bed margin mm`, `Gantry reach radius mm`, and the
  end-of-program `Park X/Y machine mm` in G53 machine coordinates.
- **Theta kinematics** — theta axis/ratio/resolver/cost settings (`Theta ratio`
  defaults to 12.03324, the measured effective ratio of the 60T→720T pulley
  pair).
  - **Theta mode** and **Theta resolver** are combos of the implemented
    strategies, so an unsupported value cannot be entered.
  - **Theta tangential speed mm/min** is the requested surface speed caused by
    A-axis bed rotation during drawing. It does not change X/Y-only output.
  - **Max bed step deg** (default `15`) is the hard limit on how far the bed may
    turn inside one drawing move. Exceeding it parks the bed and lets the gantry
    trace the move in X and Y, which is exact because the artwork is already
    clipped to the reachable disc. Lower it if a large turn mid-stroke leaves a
    drag mark, an ink blob where the machine decelerated into the corner, or a
    slight rotation of everything drawn after it; it can go to `0`, which parks
    the bed whenever a turn is needed. Cost: less rotation means more gantry
    travel, so plots get slower — measured on a dense 461-contour mandala,
    dropping 15 -> 10 deg took the total bed rotation from 30 to 52
    revolutions for the same drawing. The tuning ladder is 15 -> 10 -> 5: 15 is
    what the guard was designed around and is the current default, and 10 and 5
    are the field-tested steps down if a turn still marks the paper.
  - **Bed rotation is bounded where the machine cannot follow it.** The planner
    keeps the bed parked instead of swinging it when the axis-lock solution for
    a segment would rotate more than 15 deg, or when a stroke passes close
    enough to the bed centre that no pure-X or pure-Y machine move exists. Those
    strokes are traced by the gantry in X and Y, which is exact because the
    artwork is already clipped to the reachable disc - rotation buys no reach
    there, only risk. Pen-up moves that rotate the bed are emitted as fed moves
    (`G1 ... F... (travel)`), never as a `G0` rapid, so a `theta_wrap`
    re-registration of a whole revolution cannot outrun the A axis.
  - The converter assumes the A axis can hold **15,000 motor deg/min**
    (20.8 bed deg/s; 20,000 or 27.7 bed deg/s was verified on paper first, and
    the operator settled at 15,000 for margin) and
    **3,000 motor deg/s²** (250 bed deg/s²). Keep the controller's `$113`/`$123`
    equal to those: torque demand scales with acceleration, so `$123` is the
    setting that turns the bed's mass into force on the belt and motor.
- **Pen** — `Pen stroke mm` (the physical pen tip), Z heights, pen dwells, pen
  up/down commands, Use Z, and the two GP27 handshake options (both on by
  default since 2026-10-04; see `WSW-20261004-001`).
  - **Pen stroke mm** (`pen_diameter_mm`, default 0.3) is the real pen tip
    width. It drives ink-size reporting, pen-width compensation, the
    *Fill wide strokes* threshold, and the keep-down connector gap guard.
  - **Pen down ms** (`pen_down_ms`, default 2500) is the dwell after every
    `M3`. It covers the toolhead's warm contact seek, which starts from the
    ~1.2 mm `M5` clearance and finishes in 2-3 s.
  - **Pen up ms** (`pen_up_ms`, default 1000) is the dwell after every
    `M5`/`M3` lift. The toolhead clears in about 0.46 s measured; the extra
    margin covers the release and the settle before the next travel. With the
    GP27 handshake on, the same value is the `A` fallback dwell the `P115`
    recovery path uses when a handshake times out.
  - **Pen down first ms** (`pen_down_first_ms`, default 10000) is the dwell
    after the program's **first** `M3` only. The toolhead parks on the GP2 lift
    switch, so that one has to travel the whole retract distance before it
    reaches paper — measured at about 7 s on the installed mechanism. Without
    the longer first dwell grblHAL starts the first stroke mid-descent and the
    leading section of the path is drawn in the air. Every later `M3` starts
    from the `M5` clearance height and uses `Pen down ms`. Starting a program
    when the pen is already off GP2 — for example right after a manual
    `M3`/`M5` warm-up — only wastes the extra first-dwell time.
  - Both GP27 options require the `P115.macro` file installed on the RP23CNC,
    GP27/U3-to-`PRB` polarity verified, the flashed toolhead carrying
    `GP27_NORMAL_STATUS_ENABLED` plus `GP27_TRANSITION_LOW_MS`, F-05A passed
    (2026-09-29), and the selected pen qualified for contact/clear. The
    handshake replaces fixed `G4` dwells with a bounded controller-side
    acknowledgement; it is not a host-PC serial wait. A strict P115 timeout
    raises error 39 and aborts the running program, which is why unchecking
    **Wait for GP27 toolhead ready** is the supported fallback. The first `M3`
    carries a longer `P115` completion bound derived from **Pen down first
    ms**, because that seek starts at the GP2 lift-home switch and takes about
    7 s.
  - **Lift pen and continue if the GP27 handshake times out** is on by default
    and emits `G65 P115 ... A<lift> W2` around each normal M3/M5 transition. A
    timeout then prints a controller warning, issues `M5` to lift the pen to
    the fail-safe state, dwells for the pen-up clearance, and lets the program
    continue instead of aborting. The end-of-print full-retract wait still
    warns and dwells (`W1`) without an extra lift. It only applies with
    **Wait for GP27 toolhead ready** enabled; it trades a mid-print abort for a
    lifted pen (a missed `M3` then draws that stroke in the air) plus a console
    warning, and it masks a genuinely stuck toolhead signal - uncheck it to
    stop on a fault instead of finishing the sheet.
  - **Curve round bias** (`round_bias`, default 0.05) trades lowest-cost motion vs.
    well-rounded curves. `0` = pick the cheapest theta per segment (tends to
    axis-lock, flatter curves); higher values bias theta toward the path tangent so
    the bed rotation rounds curves (≈`tangent` mode at large values). Straights stay
    straight at any value.
  - **Theta resolver** (`theta_resolver`, default `rtheta`) uses a per-segment
    r-theta solve for `x_theta` and `y_theta`, scores both coordinated moves, and
    emits the cheaper axis choice. `dp` and `greedy` remain available as fallback
    experiments.
  - **Smoothness factor** (`smoothness_factor`, default 1.0) controls the speed vs.
    theta-smoothing trade. Lower it below `1.0` to reduce tangent tracking, reduce
    the final theta smoothing window, and expose hold-steady DP candidates for
    shorter rotation-heavy jobs. Use broad values such as `0.75`, `0.5`, or `0.25`;
    `0` is the fastest / least-smoothed setting.
  - **Theta smooth** (`theta_smooth_window`, default 2) moving-average half-window
    applied to the per-contour bed-orientation sequence. Removes bed jitter / erratic
    axis-locking; `0` disables it. Does not change the drawn shape — only how the bed
    is oriented while drawing.
- **Preview settings** — display only: playback speed, the motion estimate
  scale, and three preview colors: **Undrawn** (artwork not yet drawn), **Drawn**
  (the drawn portion / final color), and **Motion** (the generated `G1` X/Y
  pen-down path). **Show X/Y pen-down path** is on by default and overlays that
  generated path in the Motion color; turn it off when inspecting only the
  upright artwork. Pen-up travel, crosshairs, tool marker, and pen-tip footprint
  remain hidden.
- **Show machine reach guide** draws the `Gantry reach radius mm` boundary as a
  green circle around the bed center, and the preview status line reports the
  artwork radius against it. Both are measured before clipping, so artwork the
  reach cap would trim shows up as over-scale instead of quietly disappearing.
  The guide models the converter's reach radius only - it does not include the
  controller's G54 work offset, so it is not a machine-envelope check, and it is
  drawn only once a preview exists.
- **Over-scale artwork is called out, not just clipped.** A cropped plot still
  looks like a finished drawing, so when the measured artwork radius exceeds the
  reach cap the guide turns red and the preview states the ratio, e.g.
  `Artwork radius 1018.2 mm vs the 185.0 mm reach: most of the drawing is
  outside the drawable circle.` Two fits are offered next to that notice, each
  enabled only while it would still change something:
  - **Fill bed** sizes the bounding box to the drawable diameter, so the box
    edges touch the reach circle and the drawing fills the bed. The four corners
    fall outside the circle and are clipped - about 9% of the image area on a
    1440 x 1080 trace. It sizes in both directions, so a small drawing is
    enlarged to fill the bed.
  - **Fit inside** keeps every point of the drawing inside the reach circle, so
    nothing is clipped. The bounding box corners land on the ring and the box
    edges sit inside it, which leaves visible margin around the drawing. Like
    **Fill bed** it sizes in both directions, so a small drawing is enlarged to
    the largest size that still fits.
  Both fits also recenter the artwork on the bed center, clearing any manual or
  dragged `Artwork offset`. SVG document units are not millimetres: a trace
  exported as `width="1440" height="1080"` plots 1440 x 1080 mm at
  `Scale = 1.0`, which is roughly four times the drawable circle on this
  machine. For that file **Fill bed** lands at `Scale 0.2605`
  (375 x 281 mm) and **Fit inside** at `Scale 0.2085` (300 x 225 mm).
- **Fit mode.** `Scale` is normally set for you. The `Fit` setting next to it
  chooses how:
  - `Fill bed (auto)` (default) sizes the artwork's bounds to the drawable
    circle on every build.
  - `Fit inside (auto)` sizes it so every point stays inside the circle.
  - `Manual (use Scale)` uses the `Scale` field, which is the only mode where
    that field is editable.
  While an auto fit is active the `Scale` box is read-only and shows the scale
  the last build used, so nothing is hidden. The fit runs before planning, which
  means artwork authored at a physical size - a 200 mm drawing, for example -
  opens at the fitted size rather than its document size; choose `Manual` for
  literal sizes. The two buttons beside the preview select the fit as well as
  applying it, so one button press becomes the standing behaviour.
- **The preview says when it is out of date.** Building a preview is manual, so
  changing any setting that affects the plan marks the preview with
  `Settings changed since this preview - press Preview to rebuild it.` Playback
  speed, the motion estimate scale, and the preview display toggles do not.
- **Placing the artwork.** `Artwork offset X mm` and `Artwork offset Y mm` move
  the artwork's center away from the registered bed center, which is how a
  drawing whose bounding box is not its visual center gets positioned by hand.
  Both are signed and default to `0`. In the preview, **left-drag moves the
  artwork** and **Shift+left, middle, or right drag pans the view**; the wheel
  zooms and a double-click resets the zoom. Dragging updates the two fields, and
  pressing Preview re-plans with the new placement, including re-clipping to the
  reach circle. While dragging, the displayed part is the existing plan
  translated, so the reach circle - not the drawn artwork - is the authority on
  what will survive the next build.
- Pressing **Preview** shows the current build stage, percentage, and elapsed
  time. SVG parsing, motion planning, and clipping run in the background so the
  window remains responsive. The expensive contour/theta plan is built once and
  shared by the preview and complete command-list generation. Preview and Save
  G-code are temporarily disabled until that shared data is ready.
- Press **Cancel** during preview generation to stop an unexpectedly large job.
  Cancellation safely unwinds at geometry/planning checkpoints and keeps the
  last completed preview visible.
- The saved `.gcode` file is the complete generated program, including modal
  setup, M3/M5 commands, G4 dwell lines, comments, and M2. The in-app command
  list was removed; use **Save G-code** and open the file to inspect it.
- The controller-time estimate uses emitted draw-feed plans and configured pen
  dwell durations. Its **Motion estimate scale** is display-only: the current
  default `0.467368` comes from the pen-free M-06 radius sweep (`75.05 s`
  observed / `160.58 s` model). It scales draw and rapid-motion time only;
  pen dwells and emitted feeds/G-code are unchanged. The UI shows both the
  calibrated estimate and the unscaled model time. Repeat timing evidence
  before changing this machine-specific calibration.
- During playback, pen-up travel moves animate from their lift point to their
  destination using the configured travel-rate model. The highlighted rapid path
  grows only as far as the moving toolhead instead of appearing all at once.

## Notes for this machine

- Leave **Use Z axis** unchecked and keep `Pen up cmd = M5`, `Pen down cmd = M3` —
  pen height is owned by the force-control loop, not commanded Z.
- **Wait for GP27 toolhead ready** and **Lift pen and continue if the GP27
  handshake times out** are both checked by default (2026-10-04), matching how
  this commissioned machine is run. A default program emits `G65 P115 Q0` after
  the opening M5 and `G65 P115 Q1` after every subsequent M3/M5 transition,
  with the recover (`W2`/`W1`) arguments. That requires `P115.macro` on the
  RP23CNC, the GP27/U3-to-PRB wiring, and the flashed toolhead's
  `GP27_NORMAL_STATUS_ENABLED` plus `GP27_TRANSITION_LOW_MS`; if any of those is
  missing the program errors `39` mid-print. Uncheck **Wait for GP27 toolhead
  ready** to go back to the fixed `G4` dwells. F-05A passed on 2026-09-29; the
  roughly hourly timeout seen in real printing is still unexplained, so watch
  the console: with recover on, the macro prints `P115 WARNING ...`, issues
  `M5` to lift the pen, dwells, and continues on the next command.
- The converter has no XY-only export mode: every generated production program
  retains its planned A-axis words.
- The converter does not apply a pen/TMAG XY tool offset. Generated XY positions
  remain in the machine work-coordinate frame; the controller's commissioning
  macro `P100` owns magnetic center registration, the measured `pen - TMAG`
  offset, and `G54 X0 Y0` so work zero means pen tip at bed center.
- SVG document coordinates are not machine coordinates. The converter centers
  the clipped artwork at G54 zero; a document centered at `(100,100)`, for
  example, emits drawing coordinates around `(0,0)`, not `(100,100)`.
- `Bed margin mm` (default 6.35 ≈ 0.25") clips artwork inside the bed edge so the
  pen never reaches the rim.
- `Gantry reach radius mm` (default 185.0) caps the drawable circle at the
  gantry's reachable radius from the registered bed center. Because the bed
  rotates freely, the safe drawable area is this circle rather than the full
  bed; it keeps emitted coordinates inside the controller's X/Y envelope so
  artwork at the rim cannot trip `Alarm:2 - Soft limit`.
  The binding direction is **+Y**, and the edge is the controller's soft-limit
  envelope, not the switch: grblHAL sets a homed axis's envelope to
  `[max_travel + pulloff, -pulloff]` when hard limits are enabled, so `$27`
  (homing pull-off) shortens the homed end by that amount. With `$130=455`,
  `$131=451`, `$27=10` and the bed center registered at machine
  `-232.449, -195.270`, the enforced work limits are X `-212.551..222.449` and
  Y `-245.730..185.270` — so +Y is 185.270 mm from the bed center. Note that
  `$21` matters too: with hard limits off the pull-off term is zero and the +Y
  edge moves back to 195.27 mm. Re-derive this value after every HOME +
  REGISTER, since the bed center is what moves.
- **Fill.** `Fill spacing mm` sets the on-paper distance between fill lines.
  The default is `0` — outlines only — so a conversion never adds fill the
  artwork did not ask for. A positive value opts into hatching; keep it well
  under the smallest feature you want filled, because a coarse spacing leaves
  one or two short fragments inside a small closed shape. (Tone artwork with an
  embedded image or gradient gets a 4 mm starter automatically, since outlines
  only would draw nothing for a photo.)
- `Fill source` decides where the fill geometry comes from:
  - `Auto (recommended)` hatches the SVG's own shapes, and switches to image
    tone only when the artwork's tone lives somewhere the vector path cannot
    see it: an embedded `<image>`, a `url(#...)` gradient/pattern fill, or a
    photo imported directly (see below).
  - `SVG shapes (stays inside)` always hatches the SVG's own regions. Fill is
    clipped to those regions, so it cannot run over the outlines. A raster input
    has no vector regions, so it still resolves to image tone.
  - `Image tone (photos, gradients)` renders the SVG and hatches its pixels.
    It follows visible tone rather than vector regions, so a pass can overshoot
    an edge by up to `min(active spacing / 3, 1.0) mm` and hatch runs over dark
    outlines. `Raster px/unit` sets the sampling resolution; higher is more
    accurate and slower.
- **A photo or scan can be opened directly.** `Browse` accepts `.jpg`, `.jpeg`,
  `.png`, `.bmp`, `.webp`, `.tif` and `.gif` as well as `.svg`; no SVG wrapper
  is needed. The image is tone, so it always hatches from its pixels - a photo
  has no vector outlines for `SVG shapes` to use.
  - Do **not** convert the photo to a traced SVG first. A bitmap trace
    (VTracer, Inkscape "trace bitmap", most online converters) turns continuous
    tone into hundreds of flat shapes: the gradients are gone, `Fill source
    Auto` resolves to `SVG shapes` because that is all the file contains, and
    hatching each traced layer separately takes minutes. The app logs a
    `looks like a traced bitmap` warning when it sees more than forty filled
    elements and no image or gradient. Open the original `.jpg` instead: one
    fill reads the tone.
  - Tone is luminance: each pixel becomes `1 - (0.2126 R + 0.7152 G + 0.0722 B)`
    times its alpha, so a colour photo is converted to grey by the same rule a
    black-and-white print would use, and that grey drives the wave amplitude
    under `Fill pattern = gradient waves (sine_gradient)`. Dark features grow
    waves, light ones flatten them.
  - A raster is sampled at its own pixels (one view unit is one source pixel), so
    `Raster px/unit` does not apply; images wider than 2400 px are scaled down
    smoothly to that cap before sampling.
  - An auto fit has no outlines to measure, so it sizes the artwork from the
    image bounds. That needs the paper scale before the fill can be built at a
    millimetre spacing, which the preview thread resolves in one pass.
  - Practical starting point for a portrait: `Fill spacing 4`,
    `Fill pattern gradient waves (sine_gradient)`, `Gradient wave amplitude %`
    50, `Connect sine rows` on, `Fit = Fill bed`. A bed-filling photo is about
    74,000 points and four seconds; at `Fill spacing 3` it is about 131,000
    points and seven seconds.
- Any element fills the regions its **closed** outlines enclose, whether it
  declares a fill or is stroke-only. Open subpaths have no bounded interior and
  never receive fill, so fill cannot leak across artwork built from open
  segments (the Calder Hall and F15 plotter-ready exports, for example), and a
  filled-but-open path is not implicitly closed into a region whose boundary the
  pen never draws. Polyline artwork that *looks* closed still has to close its
  subpath — with `Z`, or by repeating the first point — for that region to fill.
- The Qt log reports what fill actually did after each preview, for example
  `Fill: 4 mm crosshatch, 172 hatch passes inside the SVG's own regions.` When
  there is nothing to hatch it says so and names the setting that would change
  the result.
- SVG presentation attributes are resolved through the element tree, so `fill`,
  `stroke`, `stroke-width`, `fill-opacity`, `stroke-opacity`, `visibility`, and
  `opacity` declared on a wrapping `<g>` apply to its children the way a
  renderer applies them. Line art that declares `fill="none"` on a group is
  therefore never treated as a solid silhouette, while an element that declares
  no fill anywhere still takes the SVG initial value of black. `display="none"`
  suppresses the element and its subtree, and `visibility="hidden"` or
  `"collapse"` is inherited.
- `Fill spacing`, the pattern size fields, and the curve `Tolerance` are treated
  as on-paper (machine-space) values. When the artwork is scaled below `1.0`,
  the fill and curve flattening are generated coarser in SVG space so the final
  on-paper density stays constant and the preview evaluates proportionally fewer
  contours instead of building a full-resolution lattice and shrinking it. The
  image-tone path applies the same conversion, so `Fill spacing 4` is 4 mm on
  paper whether the SVG is authored in millimetres or in a 1000-unit viewBox.
- `Fill pattern` selects the infill. In list order: `linear` (parallel lines),
  `crosshatch`, `gradient waves (sine_gradient)`, `diagonal`,
  `diagonal_crosshatch`, `triangular`, `cubic` (isometric), `diamonds`,
  `hexagonal`, `circles`, `dots`, `stipple` (tone dots), `halftone` (variable
  dots), `single line (tsp)`, `waves` (uniform sine rows), `gyroid`, and
  `concentric` (inset loops), and `terrain` (topographic contours). `waves` and
  `sine_gradient` draw the fill as sine
  rows instead of straight lines. `linear` is always one parallel-line family; darker fills
  increase density by reducing spacing, not by changing the pattern into another
  pattern. The vector fill path treats each pattern as a full layer and clips
  pattern segments to the filled contour boundary. Compound SVG paths are clipped
  as one even-odd region, so holes cut the infill layer.
- The three dot-family photo styles read the image tone directly, so like
  `sine_gradient` they are drawn at the requested pitch and ignore `Shade
  levels`:
  - `stipple` places blue-noise dots whose **density** follows tone - the
    hand-stippled portrait look. `Dot spacing mm` is the minimum gap between
    marks and each mark is a small dot (a circle about the pen tip across,
    never under 0.5 mm), so it survives the geometry filter at bed-filling
    scales. The field is deterministic, so the same photo always stipples the
    same way.
  - `halftone` places a fixed-pitch grid of dots whose **radius** follows tone
    (ink area tracks darkness, the printed-halftone look). `Fill angle deg`
    rotates the screen and `Dot spacing mm` sets the pitch.
  - `single line (tsp)` stipples the photo then walks the points
    nearest-neighbour into one continuous pen-down path - the single-line
    portrait style. `Dot spacing mm` is both the minimum point gap and the
    search grid size. It is a greedy tour, not an optimal one, so a very dense
    stipple still builds quickly.
- `Fill pattern = terrain` is the topographic-map fill: contour lines drawn the
  way a map draws a hillside, instead of `concentric`'s insets of the region's
  own outline.
  - **Image tone (photos, gradients): the picture's own shading is the
    terrain.** Darker pixels are higher ground, so the lines trace the faces
    and features of the photo - a topographic portrait - and a blown-out sky
    stays blank paper while hair and shadows fill with contours. `Fill
    spacing mm` sets the level interval from the image's own mean tone gradient
    (over its inked area), so a busy photo and a soft one both draw at roughly
    the requested pitch; the ladder always spans the ink's own tone range and
    keeps at least six bands, so a thin stroke is never lost between rungs.
    **Lines that would crowd closer than half the spacing are then skipped,
    longest line first**: a hard tone edge (an outline, a silhouette) is traced
    once or twice instead of stacking every level into a heavy band. Without
    that pass a portrait's average gap matches the request (4.2 mm at 4 mm);
    with it the portrait measures 5.7 mm because the crowded edge copies are
    gone, so a very outline-heavy drawing needs a smaller `Fill spacing` than
    a photo for the same ink coverage. `Terrain size mm` is the smoothing
    radius used before contouring - 0 follows `Fill spacing mm / 2`; larger
    values merge fine tone into broader landforms. `Shade levels` does not
    apply, because the tone is the elevation rather than a density multiplier.
  - **Flat SVG shapes (SVG shapes fill source): a synthetic height field.**
    A flat-filled element has no tone gradient inside it to trace, so the hills
    come from a deterministic fractal field and the fill still reads as
    terrain. `Terrain size mm` is then the width of one hill (0 follows
    `Fill spacing mm × 8`) and `Shade levels` tightens the contour interval to
    darken the fill, like the line patterns. The vector path clips the level
    sets to the filled shape, so a terrain fill cannot run over the artwork's
    outlines.
  - Cost is comparable to the other dense fills: the tone is sampled at half
    the contour pitch (never coarser than two source pixels) and the extracted
    segments are chained into long strokes, so one contour line is one pen-down
    move, not one per sample. The portrait above (532 x 563 px, fitted to the
    bed) loads in 0.38 s at 4 mm (825 contours, 22,000 points) and 0.8 s at
    2 mm (2,900 contours, 55,000 points), and the 4 mm program plans and saves
    in another 0.5 s (`tools\check_gcode_motion.py --strict` passes on it).
- The pattern combo lists readable labels over the stored values, so
  `sine_gradient` reads as `gradient waves (sine_gradient)` and `waves` as
  `waves (uniform sine rows)`; a settings file or a script still uses the short
  value, and either form can be typed. The gradient entry sits in the top three
  so it is visible without scrolling, and the log pane prints the converter
  core version on startup so a window left open across a change is obvious.
- Tone is amplitude **and** wiggle rate. This is SquiggleDraw's rule
  (`SquiggleDraw.pde`: `r = z/ystep*ymult` for the crest and
  `phase += z/xsmooth` for the frequency, where `z` is the pixel's darkness), so
  a dark area gets tall, tight waves and a light one gets flat, slow ones.
  `Gradient wave amplitude %` and `Gradient wave density %` are the two gains.
- `Fill pattern = sine_gradient` is the gradient fill: continuous adjacent
  sinusoids whose **amplitude follows the rendered tone**. Dark areas swell the
  waves until neighbouring rows just touch; light areas flatten them out. It
  reads a gradient as curvature, so it needs an image-tone source - `Fill source
  = Auto` already picks that for artwork with an embedded image or a
  `url(#...)` gradient/pattern fill. With `Fill source = SVG shapes` there is no
  rendered tone to read and the pattern falls back to a uniform sine hatch.
  - `Wave size mm` is the row pitch, in mm on paper. Left at `0` the rows
    follow `Fill spacing mm`; any non-zero value **overrides** `Fill spacing
    mm` for this pattern. It is the single scale for the whole wave: the
    wavelength is twice the row pitch and the crest height is
    `Gradient wave amplitude %` of the row pitch, so a 4 mm wave size gives
    4 mm rows, an 8 mm wavelength and 2 mm crests at the default 50 %.
    Measured on a 1000-unit artwork at `Fill spacing 4`: wave size 0 and 4 both
    give 4 mm rows / 8 mm waves / 2 mm crests and 65,026 points, wave size 2
    gives 2 / 4 / 1 mm and 262,236 points, and wave size 6 gives 6 / 12 / 3 mm
    and 29,192 points. The pitch drives the point count as `1 / pitch^2`, so it
    is the lever for build time.
  - `Gradient wave amplitude %` (default 50) is the crest height as a
    percentage of the row spacing. 50 makes the waves in a fully dark area
    touch the neighbouring row without crossing it; lower values keep the rows
    apart in the darkest areas.
  - `Gradient wave density %` (default 100) is how much darker tone tightens
    the squiggle, the way SquiggleDraw accumulates phase from brightness:
    `0` keeps one wavelength across the row and varies only the crest, `100`
    makes the darkest areas wiggle twice as fast as the lightest, `400` five
    times. A portrait reads best around `0`-`100`, where the tone is carried by
    crest height; higher values turn the photograph into texture, with dense
    squiggles in the shadows and long slow waves in the highlights.
  - `Connect sine rows` (on by default) joins the end of one row to the start
    of the next, so a gradient is drawn as one continuous pen-down serpentine.
    A join that would cross blank paper still breaks, so the pen lifts rather
    than drawing a mark outside the artwork.
  - `Shade levels` does not apply to this pattern: tone arrives as amplitude,
    not as extra fill families. A light gradient fades to flat hairlines rather
    than to nothing, because a hairline is the lightest mark the pen can make.
  - Render cost follows the point count, and the point count is
    `about 12 x width x height / (Fill spacing)^2` in SVG user units, so the
    spacing is the one control that matters: `Fill spacing 4` is about four
    times lighter than `2` and sixteen times lighter than `1`. A 4-6 mm spacing
    on a 1000-unit artwork builds in well under a second; 1-2 mm on the same
    artwork is hundreds of thousands of points to plan, preview and write out.
    An auto fit reads the artwork twice - once for the outlines it measures,
    then once to build the fill at the fitted scale - but the measuring pass
    carries no fill, so it costs milliseconds. `Fit = Manual` skips it.
- Consecutive passes are emitted head-to-tail, and the line families (`linear`,
  `crosshatch`, `diagonal`, `diagonal_crosshatch`, `cubic`) and the lattices
  `diamonds`/`triangular`/`hexagonal` keep the pen down between them when the
  connector is short. A dense fill is therefore drawn as one continuous zigzag
  instead of one pen cycle per pass. A connector is only drawn when it is within
  `max(Fill spacing x 0.85, Pen stroke mm x 6)`, so sparse hatching still gets
  separate passes and crosshatch still lifts between its two angle families.
  The preview draws those connectors, so a chained fill reads as one continuous
  serpentine rather than as separate strokes.
- The `waves`/`sine_gradient` rows in the vector path arrive as chained
  polylines: each sine row is one pen-down stroke rather than one contour per
  clipped sample. `sine_gradient` already emits continuous rows in the tone
  path, where `Connect sine rows` decides whether they are one stroke.
- The fill bleed margin is applied by pulling back the ends the clip creates,
  never by offsetting the region, so a pass cannot land outside the fill region.
  This matters for bitmap-traced artwork built from thousands of overlapping
  subpaths, where offsetting each subpath independently cannot preserve the
  even-odd region.
- `diamonds`, `triangular`, `hexagonal`, and `circles` each have a dedicated size
  field (`Diamond size mm`, `Triangle size mm`, and so on). When that field is
  left at `0`, the cell size falls back to `Fill spacing mm × 6` rather than
  `Fill spacing mm` alone, so an unset lattice does not degrade into an
  impractically dense (and slow) mesh.
- `Shade levels > 1` turns fill darkness into hatch density: darker fills receive
  denser spacing while preserving the selected fill pattern. Fill darkness comes
  from the fill colour, or from the stroke colour for closed line-art outlines.
  White and fully transparent elements are skipped, because a single pen cannot
  show them.
- [`../samples/svg/raster-shading-math.svg`](../samples/svg/raster-shading-math.svg)
  is an editable visual reference for the tone-to-hatch mathematics.
- [`../samples/svg/gradient-sine-demo.svg`](../samples/svg/gradient-sine-demo.svg)
  is a gradient sample: a linear fade, a radial orb and a vertical band. Select
  it with `Fill spacing 3`, `Fill pattern sine_gradient` and the default
  `Fill source Auto` to see tone as wave amplitude.
- When an SVG is selected, the Qt app inspects how the artwork declares its
  fill (filled elements, stroke-only elements, embedded images, paint servers)
  and says in the log what `Auto` will do with it. Tone-carrying artwork also
  gets tone-friendly starter values (`Shade levels = 4`, `Shade angle step = 45`),
  and gradient paint also logs a reminder that `Fill pattern = sine_gradient`
  plots it as continuous adjacent sinusoids.

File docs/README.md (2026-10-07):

# Documentation Map

Use this page to find the shortest authoritative path for a task. Do not read
the entire documentation tree before working.

For a visual overview of this process, open
[`codex-documentation-flow.html`](codex-documentation-flow.html).

For the current end-to-end system data paths (normal plotting, P100 startup
registration, toolhead lifecycle, faults, and commissioning), open
[`system_data_flow.html`](system_data_flow.html). Its comparison baselines and
update procedure are in
[`architecture/SYSTEM_DATA_FLOW_RECORD.md`](architecture/SYSTEM_DATA_FLOW_RECORD.md).
For the intended P100 command/sensor/reply ownership by stage, open
[`p100-data-movement.html`](p100-data-movement.html).

## Start by task

| Task | Read first | Current source of truth |
|---|---|---|
| Architecture, dependency, impact, or cross-subsystem investigation | [`../ONTOLY_PROMPT.md`](../ONTOLY_PROMPT.md) | Ontoly graph for code topology; listed subsystem authorities for physical and runtime facts |
| Windows converter UI or behavior | [`../software/README.md`](../software/README.md) | Code under `software/`; behavior in `software/README.md` |
| CMYK calibration print/scan analysis (AI handoff) | [`testing/CMYK_CALIBRATION.md`](testing/CMYK_CALIBRATION.md) | `software/generator_tabs/cmyk_sheet.py`, `tools/cmyk_calibrate.py` |
| Converter algorithms or historical tradeoffs | [`HANDOFF.md`](HANDOFF.md) relevant section only | Code under `software/converter_core/`; deep rationale in `HANDOFF.md` |
| Kaleidoscope designs (image to mirrored artwork) | [`../software/README.md`](../software/README.md) | `software/qt_kaleidoscope.pyw` and `software/converter_core/kaleidoscope.py` |
| RP23CNC/grblHAL work | [`../firmware/README.md`](../firmware/README.md) | Relevant file under `firmware/grblhal/` |
| Pen-pressure firmware | [`../firmware/pen_pressure/README.md`](../firmware/pen_pressure/README.md) | `firmware/pen_pressure/` |
| Power distribution | [`hardware/POWER_DISTRIBUTION.md`](hardware/POWER_DISTRIBUTION.md) | `hardware/WIRING_TABLE.md` plus the power-only schematic |
| Wiring or pin assignment | [`hardware/WIRING_TABLE.md`](hardware/WIRING_TABLE.md) | `hardware/WIRING_TABLE.md` |
| Part selection or electrical rating | [`hardware/BOM.md`](hardware/BOM.md) | `hardware/BOM.md` |
| Toolhead pen mount or spring mechanics | [`hardware/TOOLHEAD_MECHANICS.md`](hardware/TOOLHEAD_MECHANICS.md) | `hardware/TOOLHEAD_MECHANICS.md` |
| Subsystem interface or units | [`integration/INTERFACES.md`](integration/INTERFACES.md) | `integration/INTERFACES.md` |
| ioSender/converter streaming readiness | [`integration/IOSENDER_CONVERTER_COMPATIBILITY_REVIEW.md`](integration/IOSENDER_CONVERTER_COMPATIBILITY_REVIEW.md) | Review plus F-02, M-06, F-05, and P100 commissioning evidence |
| Current priorities | [`project/ROADMAP.md`](project/ROADMAP.md) | `project/ROADMAP.md` |
| Test or bench work | [`testing/TEST_PLAN.md`](testing/TEST_PLAN.md) | Test plan plus `report/lab-notes/` evidence |
| Why a lasting decision was made | [`decisions/`](decisions/) | Applicable ADR |
| What changed recently | [`changes/INDEX.md`](changes/INDEX.md) | Categorized change note |
| Chronological successes and failures | [`project/ENGINEERING_LOG.md`](project/ENGINEERING_LOG.md) | Engineering log |

## Document roles

Each type has one job:

- **Current-state documents** describe how the project works now.
- **Change notes** explain one meaningful change, its verification, and risks.
- **Engineering log** records milestones, failures, measurements, and decisions
  in chronological order. Its generated topic index links to those same entries
  without copying their bodies.
- **Roadmap** tracks incomplete and completed project work.
- **ADRs** preserve decisions with lasting architectural consequences.
- **Lab notes** contain raw physical-test evidence.
- **Git history** remains the record for incidental edits and mechanical
  cleanup that do not warrant a separate narrative.

Avoid copying the same detailed explanation into multiple documents. Put the
full detail in the authoritative document and link to it elsewhere.

## Large reference documents

[`HANDOFF.md`](HANDOFF.md) is a deep technical reference and historical design
record. Search it by topic; it is not required front-to-back reading.

[`project/ENGINEERING_LOG.md`](project/ENGINEERING_LOG.md) is intentionally
append-only and will grow. Search by component, test ID, status, or error text.

## Validation

After documentation changes:

```powershell
python tools\docs_index.py --write
python tools\docs_index.py --check
```

The first command rebuilds change indexes from note metadata. The second checks
generated indexes, note metadata, duplicate IDs, and local Markdown links.

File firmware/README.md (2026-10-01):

# Firmware - machine controller + pen pressure

Runs on the machine side, fully separate from the host `software/`. Two
independent subsystems:

Primary RP23CNC hardware and board-support reference:
[`phil-barrett/RP23CNC`](https://github.com/phil-barrett/RP23CNC).
Current motion-controller tasks are maintained in
[`../docs/project/ROADMAP.md`](../docs/project/ROADMAP.md).

| Folder | Role | Target |
|---|---|---|
| [`grblhal/`](grblhal/) | Motion control - parses the host G-code and drives the X/Y/A steppers | RP23CNC / RP23U5XBB running grblHAL on RP2350 |
| [`pen_pressure/`](pen_pressure/) | Closed-loop pen contact-force control, calibration fixtures, and TMAG5273 magnetic sensing | Toolhead-mounted SparkFun Pro Micro RP2350 |

## Why this split

Writing a G-code parser plus acceleration-aware motion planner from scratch is
the hard 80% of plotter firmware. **grblHAL already does it** and has an
RP2040/RP2350 port, so motion is configuration, not new code. The selected
motion controller is the RP23CNC / RP23U5XBB 5-axis grblHAL controller with the
Ethernet adapter. The pen-pressure loop is a distinct real-time concern. Its
controller placement is now accepted: a separate SparkFun Pro Micro RP2350 on
the toolhead owns force control and TMAG5273 sensing so those workloads remain
isolated from grblHAL motion timing. See
[`../docs/decisions/ADR-002-toolhead-placement.md`](../docs/decisions/ADR-002-toolhead-placement.md).

## Integration contract

```text
host .gcode -> grblHAL on RP23CNC: X/Y/A motion, spindle/tool output state
                                          |
                                          +-> pen-pressure MCU
                                          M3 = ENGAGE (resume force loop, seek paper)
                                          M5 = PEN_CLEAR (release paper, add clearance pulse)
```

- **Selected controller** - RP23CNC / RP23U5XBB with Ethernet adapter. Use its
  X/Y/A step-dir outputs, opto-isolated limit inputs for homing, and
  spindle-enable or another suitable digital output for the pen-pressure
  ENGAGE/LIFT signal. The spindle-enable output is active-high by default,
  which is inverted from the toolhead's active-low optocoupler input, so the
  controller sets `$16=1` (invert spindle enable); `M3` then engages and `M5`
  lifts (F-05, 2026-09-23). See
  [`grblhal/config/machine-settings.md`](grblhal/config/machine-settings.md).
- **`A` is motor-shaft degrees** - the host already applied the measured 12.0332:1 pulley
  ratio. Configure grblHAL's A steps-per-unit as *motor steps per degree*; do
  **not** reapply the ratio. Or set `Theta ratio = 1` in the host and own the
  ratio here. Pick exactly one place.
- **Settle handshake** - fixed `G4` dwells remain the default. The optional
  controller-resident `P115.macro` instead observes GP27/`PRB` after M3/M5:
  it requires a new inactive-to-active completion edge, then returns only when
  contact-ready or pen-clear is proven. Its finite timeout raises error 39
  before the following motion block; an opt-in recover mode can instead lift
  the pen (`M5`) and continue on a long print. The converter emits `P115` only
  when its commissioning-only GP27 option is enabled. Normal `M5` ends at the load-cell
  release threshold plus a calibrated clearance pulse; it does not travel to
  the distant `LIFT_HOME` switch. `P115` and the toolhead GP27 output are
  enabled once F-08, force, and clearance commissioning pass; F-05A passed on
  2026-09-29, which unblocks the converter option, though it still ships off.
  To keep the inactive-to-active edge observable, the toolhead now holds GP27
  inactive for a guaranteed 50 ms on every M3/M5 transition
  (`GP27_TRANSITION_LOW_MS`) and
  holds the published contact-ready level through the hold loop's bounded
  corrections (release after 500 ms beyond the 20 g relief bound,
  `CONTACT_READY_LOST_MS`), so the level cannot chatter in `HOLD_FORCE`.
- **Pen full retract and park** - the end of a saved program requests the
  toolhead's full retract to the GP2 lift-home switch by asserting the already
  installed Aux0/GP28 arm (`M65 P0`), waits the toolhead's own 3.0 s
  `BOOT_LIFT_TIME_MS` retract bound, releases it (`M64 P0`), and then parks off
  the bed with a `G53 G0` machine-coordinate move. The controller file
  `macros/P116.macro` exposes the same sequence as a manual ioSender button
  (`PEN UP + PARK` -> `G65 P116`) for taking paper off between runs; it proves
  the normal M5 clearance with `P115`, then runs `G65 P111` to home X/Y before
  the park. The home is required, not optional: a `G53` park on an unhomed
  controller has no frame to park in and travels the full commanded distance
  from an unknown position, which drove the gantry into the `-Y` end on
  2026-09-30. The converter's program-end park inherits that precondition from
  the `G65 P113` that precedes every run.
- **Homing and bed registration** - X/Y physical switches establish machine
  coordinates. A controller-resident `P100.macro` then uses the existing
  Aux0/GP28 arm and GP27/U3 return to capture a full center-magnet raster,
  compute an area centroid, register G54 X0/Y0, and scan the outer magnet twice
  to register G54 A0. The Pro Micro supplies only readiness and thresholded
  magnetic state; it never claims one threshold edge is the center. Send `M5`
  and verify the toolhead is retracted before any homing or scan. The verified
  production entry point is `G65 P113`: its unified wrapper performs the safe
  pen clear and dwell, the one physical X/Y `$H`, and then `G65 P100 Q0`.
  Q3/Q4 remain locked. See
  [`grblhal/HOMING_AND_MAGNETIC_CALIBRATION.md`](grblhal/HOMING_AND_MAGNETIC_CALIBRATION.md).
  Two named constants, `#<axis_center_correction_x>` and `_y`, move the
  registered origin onto the bed's true rotation axis before the G54 write:
  the centre magnet is not guaranteed to sit exactly on that axis, and a
  constant error there displaces every drawing. As of 2026-10-01 the X
  correction is `+1.25` mm; the accept/reject test is
  `samples/gcode/center-registration-check.gcode` after `G65 P113` (a cross at
  `G54 X0 Y0`, half a bed revolution, the same cross again - they must
  coincide), or, faster and without paper, a magnet directly under the lifted
  pen that stays centred while the bed rotates. That check passed on
  2026-10-01. See `RPSW-20261001-002` and
  [`grblhal/macros/README.md`](grblhal/macros/README.md).
- **Candidate probe capture** - the 2026-09-10/11 motor-inert candidate
  proved direct and actual GP27/U3 `PRB` transitions, A-axis G38 capture, and
  the automated non-motion `G65 P100 Q1` readiness/release handshake.
  GP27/U3 is assigned to `PROBE SIG` with `$6=1`. The old `P100 Q2` branch
  proved that `$H` works from an SD macro, but Q5 subsequently revealed that
  grblHAL streams every `$H` in P100 even inside false O-word branches. P100
  now contains no `$H`; `G65 P111` owns the one intentional X/Y home before
Q5. The bounded Q5 center-magnet raster passed, placing TMAG at
`MPos:-232.013,-218.775`; it leaves G54/A unchanged. P112 now stages the
outer-index survey at G53 X `-10.5` mm (about 2.2 mm inboard of the measured
radius to clear the X home pull-off) without writing G54. Three installed
two-footprint surveys (4331.818 / 4331.930 / 4332.153) measure 4331.97 A
motor degrees per bed turn, so its bounded spacing gate is `4332 +/- 10`.
The revised installed P112 run completed
and parked at its pass-two center `MPos:-10.500,-218.363,A8610.084` without a
G54 write; the operator visually confirmed the index magnet centered beneath
the TMAG chip. With the toolhead still at that verified position, the operator
issued `G10 L20 P1 A0`; `$#` then reported `G54` A offset `17281.142`, proving
the current physical index is G54 A0 with no motion. Q0/Q3/Q4, coordinate
semantics, and normal-status timing gates remain closed before production use.
Q5 now uses a 5 mm row pitch and a requested 2000 mm/min G38 feed. The
smaller pitch doubles the number of 100 mm rows, so it improves sampling
density while the doubled requested line rate keeps total scan time comparable.
The installed X/Y maximum rates remain 1500 mm/min until a separate loaded-rate
test authorizes an increase.

The manual magnetic G54 frame is now physically verified. A final Q5 returned
TMAG to `MPos:-232.125,-218.325,A17281.142`; the stationary
`G10 L20 P1 X0 Y-29.4892` write produced
`G54:-232.126,-188.835,0.000,17281.142`. `G54 G0 X0 Y0` then placed the pen
tip exactly at the center magnet by visual inspection. This replaces both
temporary G54 references, but it does not unlock P100 Q0/Q3/Q4.

## Status

The RP23CNC grblHAL baseline now boots over native USB: F-01 passed on
2026-08-14 with the RP23U5XBB board target, four-axis XYZA build, W5500, and
SD/Ymodem support. Installed TB6600 signal response and unloaded X/Y/A motion
bring-up have since been partially commissioned: A M-01/M-02/M-04/M-05 and
X/Y M-01/M-02 checks passed for their documented scopes. The Y M-03 check
measured exactly 100 mm at `$101=80.000000`; the current owner-caliper-verified
X setting is `$100=80.00000`. X/Y physical homing then passed single-axis and
repeated combined tests using the east/south NC switches, with Z/A excluded.
The guarded X/Y software envelope is enabled at `$130=455.000` mm and
`$131=446.000` mm with `$20=$40=1` and hard limits disabled (`$21=0`);
controlled boundary-rejection testing remains open. Pen-free G54 magnetic
registration is hardware-verified through P113, including on the production
integrated toolhead build with the magnetic commissioning gate enabled
(`RPSW-20260924-001`, 2026-09-24); pen-loaded behavior remains open.
For guarded pen-free commissioning, the operator manually established a
temporary pen-corrected G54 X/Y reference from the center magnet on 2026-09-06;
the measured `sensor_to_pen` vector is `(0.000, -30.100)` mm. After the
guarded Y envelope changed the homed machine frame, that reference was
refreshed at `MPos:-232.900,-191.200`; the operator also chose a temporary G54
`A0` reference for a pen-free converter run, which returned exactly to its
references. This is not P100 or magnetic A registration and must be overwritten
before production drawing.
A dual-core toolhead implementation now exists at
[`pen_pressure/pro_micro_rp2350_toolhead/pro_micro_rp2350_toolhead.ino`](pen_pressure/pro_micro_rp2350_toolhead/pro_micro_rp2350_toolhead.ino)
for integrated control of the DRV8833, CS1238, TMAG5273, and M3/M5 command
input. Core 0 owns pressure/safety and Core 1 owns magnetic acquisition and the
two-phase readiness/scan handshake. CS1238 acquisition is suspended while the
verified-lifted magnetic mode is active. With the PC817C module, GP29 M3/M5 and GP28 `HOME_ARM`
inputs are externally pulled HIGH and optocoupler assertions pull them LOW;
the integrated sketch is configured for that active-low interface. F-05/E-18
must still establish the RP23CNC ENA/Aux0 state mapping. Compile-time safety
gates deliberately prevent uncommissioned actuator and magnetic operation.
The separate normally-open `LIFT_HOME` microswitch is installed from GP2 to
local `TOOL_GND`; the integrated firmware configures it as an active-low
pull-up input and reports it through native USB and GP20/GP21 service UART.
The service interface uses Arduino-Pico `Serial2` (hardware UART1), and the
integrated firmware prints its service-UART-ready line before other
initialization. Its telemetry writer does not require a complete record to fit
in the UART FIFO, so GP20 telemetry is not silently suppressed.
The current supervised bench source uses GP2 as the full-retract origin for a
single bounded M3 descend (10 ms DOWN pulses while far from the paper, then
5 ms pulses once force rises above about 1 g, each with the full 300 ms settle
near contact). It enters `HOLD_FORCE` at the lower edge of the 40 g target band,
and its moving-average hold loop uses individual 5 ms corrective pulses only
outside the 25–55 g band—never a continuous motor command; after normal M5, it
retains the short 100 ms M3 path. T-01G repeatability and T-02/T-01J powered
seek qualification remain open, so keep the RP23CNC M3/M5 harness disconnected
during initial seek validation and retain access to the toolhead power cutoff.
Smaller Arduino sketches also exist for safer bring-up, including a GP2/GP20
LIFT_HOME UART-only diagnostic with no motor-related pin activity:
[`pen_pressure/bench_motor_command/bench_motor_command.ino`](pen_pressure/bench_motor_command/bench_motor_command.ino)
tests only GP29 and the DRV8833, and
[`pen_pressure/bench_sensors/bench_sensors.ino`](pen_pressure/bench_sensors/bench_sensors.ino)
tests only the historical HX711 and TMAG5273 paths.
The prior powered pen-tip HX711 diagnostic remains available only as historical
evidence at
[`pen_pressure/e07b_hx711_actuator_steps/e07b_hx711_actuator_steps.ino`](pen_pressure/e07b_hx711_actuator_steps/e07b_hx711_actuator_steps.ino).
It uses a 3.3 V USB-to-TTL service adapter on GP20/GP21 rather than the Pro
Micro USB-C port, and limits every actuator command to one short step followed
by DRV8833 sleep. Its `r` command performs one bounded 12-down/12-up trace at
fixed 10 ms pulses, sampling HX711 after each motion so a short scale video can
be reconciled with the serial trace without a human round trip per point. This
is a temporary bench/service interface, not part of the normal plotter control
path. It must not be used to calibrate the CS1238.
The native-USB, motor-inert
[`pen_pressure/e07c_cs1238_sensor_bringup/e07c_cs1238_sensor_bringup.ino`](pen_pressure/e07c_cs1238_sensor_bringup/e07c_cs1238_sensor_bringup.ino).
characterizes the received ADC at 40/640/1280 SPS. The integrated controller
now has the matching CS1238 source backend, but all calibration and motion
gates remain false until E-07C/E-08C/E-09C evidence and a separately bounded
actuator-response test are accepted.
Use [`../docs/project/ROADMAP.md`](../docs/project/ROADMAP.md) for active
work, [`grblhal/HOMING_AND_MAGNETIC_CALIBRATION.md`](grblhal/HOMING_AND_MAGNETIC_CALIBRATION.md)
for P100 design/commissioning, and
[`../docs/testing/TEST_PLAN.md`](../docs/testing/TEST_PLAN.md) for acceptance
conditions.

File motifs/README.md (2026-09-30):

# Motif library

Two folders of black-on-white PNGs for the Kaleidoscope Converter's **Motif
folder...** button.

| Folder | What it is | Files |
| --- | --- | --- |
| `nature-engravings/` | Organisms cut from public-domain engraving plates - Ernst Haeckel's *Kunstformen der Natur* and botanical/zoological plates - downloaded at 1280 px and cropped to individual drawings. Black ink line work with real hatching, which is the same vocabulary as the reference kaleidoscope artwork. | 88 |
| `nature/` | Real organism silhouettes from [PhyloPic](https://www.phylopic.org): birds, cats, elephants, fish, dolphins, spiders, ants, jellyfish, butterflies, crabs, tortoises, plants and more, traced by scientists and published under CC0 / public domain / CC BY. | 150 |
| `nature-drawn/` | The first, code-drawn set (`tools/make_nature_motifs.py`): schematic leaves, flowers, trees, shells, insects and small animals. Flat and cartoon-like, but tidy and very light to plot. | 110 |

`nature/CREDITS.md` lists the taxon, contributor, licence and source of every
downloaded file, and `nature/manifest.json` carries the same data for tooling.
`nature-engravings/CREDITS.md` does the same for the plates.

## Use them

1. Start `kaleidoscope.bat`.
2. Tick **Generate a random pattern**.
3. Press **Motif folder...** and pick `motifs/nature-engravings` for the
   engraved plates (or `motifs/nature` for silhouettes); this also ticks **Use
   natural motifs in patterns**.
4. Browse `Seed`; set `Intricacy`. In motif mode each shape is drawn at full
   size with two smaller nested copies inside it, rings are separated by thin
   bundles with flower studs and bead rows, and the copies overlap.

Only the motifs a seed actually places get traced, and traced results are
cached, so pointing at 150 files costs nothing until they are used.

## Regenerate, extend or swap

```powershell
python tools\make_nature_motifs.py --out motifs\nature-drawn       # redraw the drawn set
python tools\fetch_phylopic_motifs.py --out motifs\nature --limit 150   # more organisms
python tools\fetch_engraving_motifs.py --out motifs\nature-engravings --plates 30
python tools\fetch_nature_motifs.py --out motifs\nature --limit 120    # Commons silhouettes
```

- `make_nature_motifs.py` draws every shape from code; add a function plus a
  `CATALOGUE` line to extend it.
- `fetch_phylopic_motifs.py` pulls vector organism silhouettes from PhyloPic,
  rasterises them with Qt and writes the credits files.
- `fetch_engraving_motifs.py` pulls public-domain engraving plates from
  Wikimedia Commons, crops the drawing area into organisms, drops caption
  bands, and writes the credits files. Plates have no clean gutters, so crops
  come from an overlapping grid over the drawing area and are then filtered by
  ink density and spread.
- `fetch_nature_motifs.py` pulls from Wikimedia Commons (silhouette categories,
  pressed herbarium leaves). Wikimedia throttles bulk downloads hard, so run it
  in small batches and expect pauses.

Any folder of dark-on-light PNG/JPG artwork works too: hand-drawn scans,
herbarium sheets, your own pen sketches.

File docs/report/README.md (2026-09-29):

# System Integration in Robotics — report

Working area for the end-of-semester report on this project. Drop drafts, figures,
and exports here.

Use [`LAB_NOTE_TEMPLATE.md`](LAB_NOTE_TEMPLATE.md) for bench work. Keep dated
notes under `lab-notes/` so measurements and design changes can be cited later.
The project-wide chronology is maintained in
[`../project/ENGINEERING_LOG.md`](../project/ENGINEERING_LOG.md); use it to build
the report timeline, locate supporting commits or lab evidence, and discuss
setbacks, troubleshooting, rejected designs, and lessons learned in sequence.

The report is about **integrating the subsystems** into one working pipeline:
host conversion software → motion controller → force-controlled pen. The repo is
organized along those subsystem lines so each maps to a report section. Use the
level-0 and level-1 system names and seams from
[`../architecture/SYSTEM_ARCHITECTURE.md`](../architecture/SYSTEM_ARCHITECTURE.md)
when the report defines system boundaries.
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

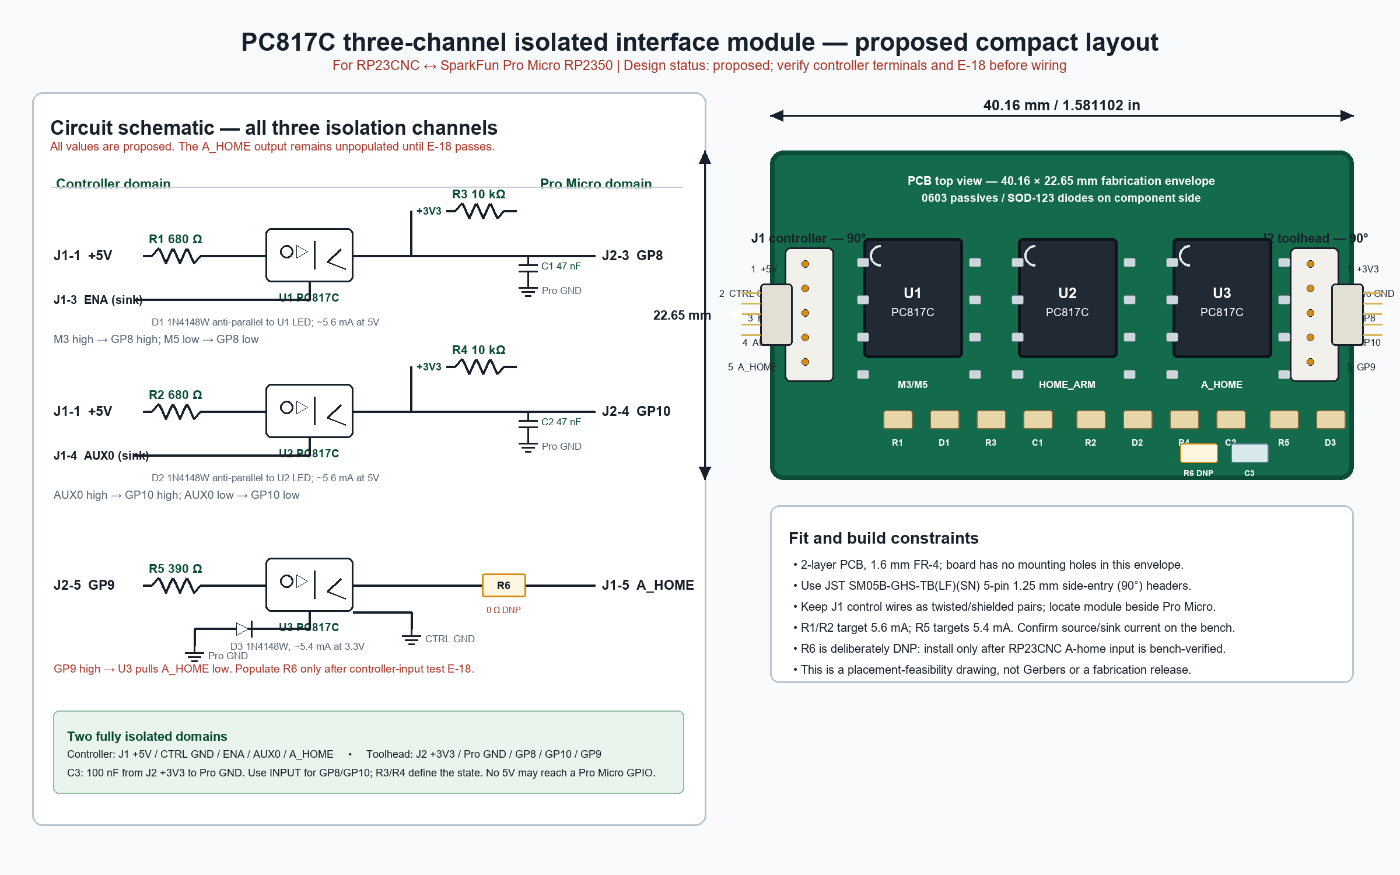
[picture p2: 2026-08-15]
pc817-three-channel-module-proposal.png

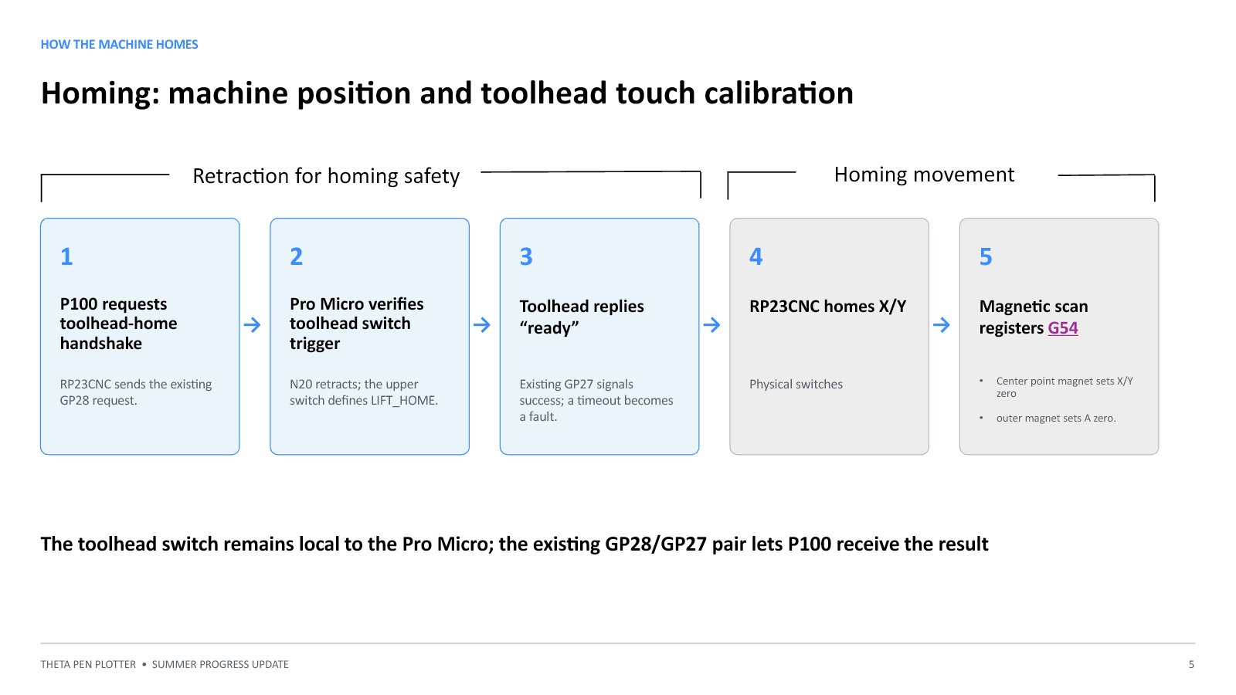
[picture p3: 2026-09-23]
docs/report/Theta_Pen_Plotter_Summer_Progress_Update/slide-5.png

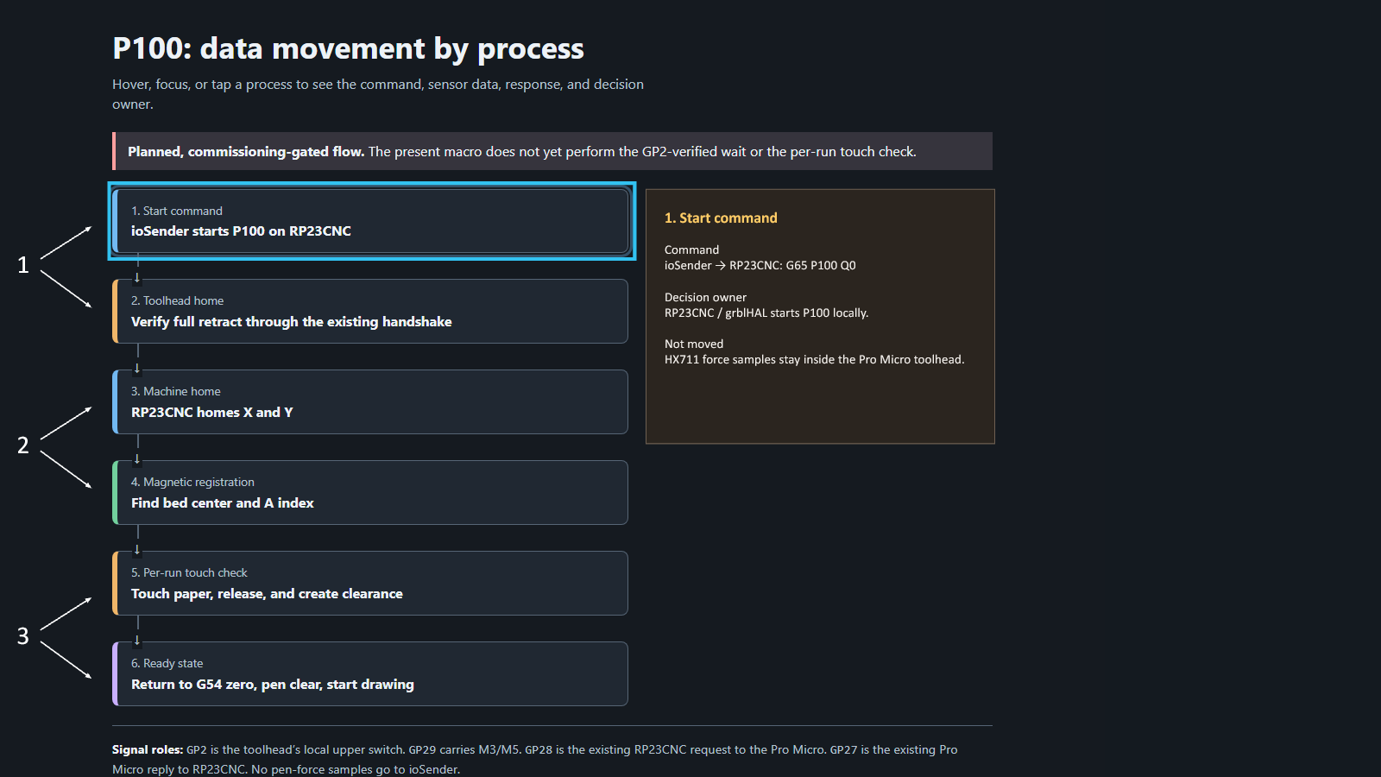
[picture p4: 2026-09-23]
docs/report/Theta_Pen_Plotter_Summer_Progress_Update/slide-6.png

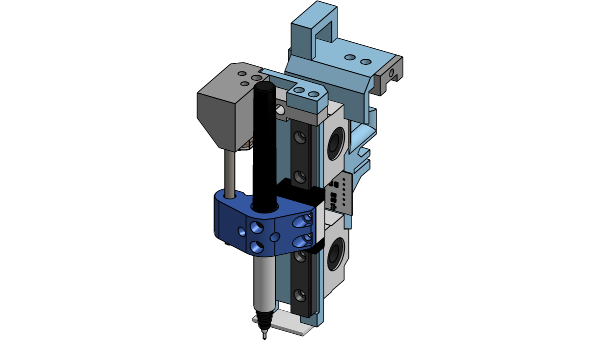
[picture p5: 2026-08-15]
docs/hardware/cad/scrapyard-v2-toolhead-thumbnail.png

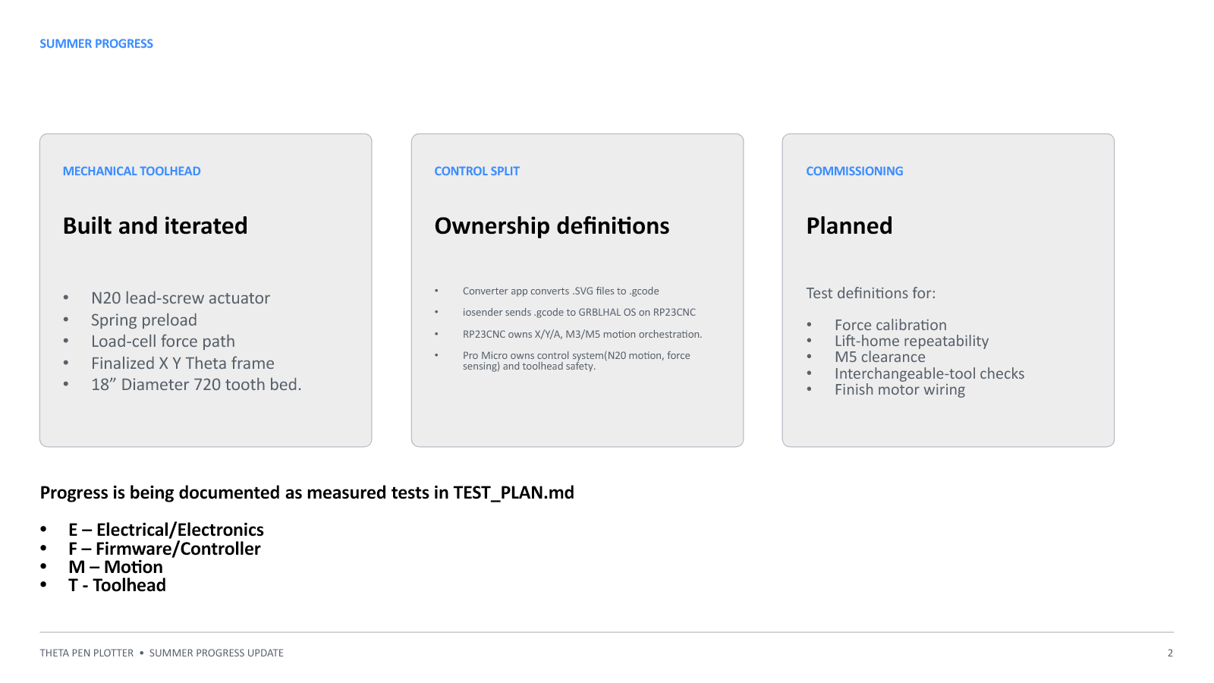
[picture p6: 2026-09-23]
docs/report/Theta_Pen_Plotter_Summer_Progress_Update/slide-2.png

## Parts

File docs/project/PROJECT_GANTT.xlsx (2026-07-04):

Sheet: Dashboard
XYTheta Pen Plotter Project Dashboard
Schedule baseline: 2026-06-01 through 2026-12-29. Change dates and statuses on the Gantt sheet.
TOTAL TASKS |  |  | COMPLETE | IN PROGRESS | BLOCKED
49 |  |  | 1 | 0 | 0
Phase | Tasks | Complete | Average Progress
Phase 0 - Repository | 1 | 1 | 100%
Phase 1 - Electrical | 12 | 0 | 0%
Phase 2 - Controller | 6 | 0 | 0%
Phase 3 - Single Axis | 5 | 0 | 0%
Phase 4 - Three Axis | 6 | 0 | 0%
Phase 5 - Toolhead | 8 | 0 | 0%
Phase 6 - Integration | 5 | 0 | 0%
Phase 7 - Validation | 6 | 0 | 0%
Current Focus
Complete the Phase 1 bench worksheet before connecting motors or the toolhead to RP23CNC. Record evidence in lab notes, then update ROADMAP.md and this workbook together.
Status Legend
Not Started | In Progress | Blocked | Complete

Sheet: Gantt
Theta Pen Plotter Project Gantt
Editable schedule generated from docs/project/ROADMAP.md. Update task inputs, then keep roadmap evidence/checklists authoritative.
Edit columns D-H, J-M. End dates and summaries are formula-driven. Timeline bars update from Start, End, and Status.
ID | Phase | Task | Owner | Status | Priority | Duration | Start | End | Progress | Predecessor | Evidence / Exit Proof | Notes | 2026-06-01 | 2026-06-08 | 2026-06-15 | 2026-06-22 | 2026-06-29 | 2026-07-06 | 2026-07-13 | 2026-07-20 | 2026-07-27 | 2026-08-03 | 2026-08-10 | 2026-08-17 | 2026-08-24 | 2026-08-31 | 2026-09-07 | 2026-09-14 | 2026-09-21 | 2026-09-28 | 2026-10-05 | 2026-10-12 | 2026-10-19 | 2026-10-26 | 2026-11-02 | 2026-11-09 | 2026-11-16 | 2026-11-23 | 2026-11-30 | 2026-12-07 | 2026-12-14 | 2026-12-21 | 2026-12-28
P0-01 | Phase 0 - Repository | Repository organization and documentation baseline | Codex | Complete | High | 5 | 2026-06-01 | 2026-06-05 | 100% |  | ROADMAP Phase 0 | Completed before hardware bring-up
P1-01 | Phase 1 - Electrical | Inventory and photograph RP23CNC kits and PCB revision (E-16) | Project Owner | Not Started | High | 2 | 2026-06-15 | 2026-06-16 | 0% |  | Photo + E-16 lab note
P1-02 | Phase 1 - Electrical | Solder and inspect RP23CNC connectors and Ethernet components (E-17) | Project Owner | Not Started | High | 4 | 2026-06-17 | 2026-06-20 | 0% | P1-01 | Photos + continuity results
P1-03 | Phase 1 - Electrical | Identify driver, sensor, and module revisions | Project Owner | Not Started | Medium | 2 | 2026-06-17 | 2026-06-18 | 0% | P1-01 | Component photos
P1-04 | Phase 1 - Electrical | Verify S-120-12 labels, earth continuity, and no-load output (E-11) | Project Owner | Not Started | High | 2 | 2026-06-22 | 2026-06-23 | 0% | P1-02 | E-11 lab note
P1-05 | Phase 1 - Electrical | Measure stepper coil pairs and resistance (E-01) | Project Owner | Not Started | High | 1 | 2026-06-24 | 2026-06-24 | 0% | P1-04 | E-01 results
P1-06 | Phase 1 - Electrical | Document TB6600 switches and verify STEP/DIR behavior (E-02/E-03) | Project Owner | Not Started | High | 3 | 2026-06-25 | 2026-06-27 | 0% | P1-05 | E-02/E-03 results
P1-07 | Phase 1 - Electrical | Characterize N20 actuator current (E-05/E-06) | Project Owner | Not Started | High | 2 | 2026-06-29 | 2026-06-30 | 0% | P1-04 | E-05/E-06 results
P1-08 | Phase 1 - Electrical | Calibrate load cell and characterize HX711 rate/noise (E-07/E-08) | Project Owner | Not Started | High | 4 | 2026-07-01 | 2026-07-04 | 0% | P1-07 | Calibration data
P1-09 | Phase 1 - Electrical | Verify TMAG5273 readings and geometry (E-09) | Project Owner | Not Started | Medium | 2 | 2026-07-06 | 2026-07-07 | 0% | P1-08 | E-09 results
P1-10 | Phase 1 - Electrical | Configure and load-test 6 V buck converter (E-14/E-15) | Project Owner | Not Started | High | 3 | 2026-07-08 | 2026-07-10 | 0% | P1-07 | E-14/E-15 results
P1-11 | Phase 1 - Electrical | Complete power budget, fuses, wire gauges, and wiring evidence | Project Owner | Not Started | High | 4 | 2026-07-13 | 2026-07-16 | 0% | P1-04,P1-10 | BOM + wiring table
P1-GATE | Phase 1 - Electrical | Milestone: electrical characterization gate | Project Owner | Not Started | High | 1 | 2026-07-17 | 2026-07-17 | 0% | P1-11 | Phase 1 checklist | All compatibility gates resolved
P2-01 | Phase 2 - Controller | Build or obtain RP23CNC-compatible grblHAL firmware | Codex | Not Started | High | 5 | 2026-07-20 | 2026-07-24 | 0% | P1-GATE | Build record
P2-02 | Phase 2 - Controller | Archive source commits, board target, plugins, and options | Codex | Not Started | Medium | 2 | 2026-07-23 | 2026-07-24 | 0% | P2-01 | Firmware README
P2-03 | Phase 2 - Controller | Flash board and verify USB/Ethernet communication (F-01) | Project Owner | Not Started | High | 3 | 2026-07-27 | 2026-07-29 | 0% | P2-01 | F-01 result
P2-04 | Phase 2 - Controller | Verify converter parser subset and unpowered STEP/DIR (F-02/F-03) | Project Owner | Not Started | High | 3 | 2026-07-30 | 2026-08-01 | 0% | P2-03 | F-02/F-03 results
P2-05 | Phase 2 - Controller | Verify limit inputs, M3/M5 output, and settings persistence (F-04/F-05/F-06) | Project Owner | Not Started | High | 4 | 2026-08-03 | 2026-08-06 | 0% | P2-04 | F-04 to F-06 results
P2-GATE | Phase 2 - Controller | Milestone: controller baseline gate | Project Owner | Not Started | High | 1 | 2026-08-07 | 2026-08-07 | 0% | P2-05 | Phase 2 checklist
P3-01 | Phase 3 - Single Axis | Configure one TB6600 and connect motor without mechanics | Project Owner | Not Started | High | 2 | 2026-08-10 | 2026-08-11 | 0% | P2-GATE | Configuration record
P3-02 | Phase 3 - Single Axis | Complete low-speed jog and temperature test (M-01) | Project Owner | Not Started | High | 2 | 2026-08-12 | 2026-08-13 | 0% | P3-01 | M-01 result
P3-03 | Phase 3 - Single Axis | Ramp rate/acceleration and set conservative margin (M-02) | Project Owner | Not Started | High | 3 | 2026-08-14 | 2026-08-16 | 0% | P3-02 | M-02 result
P3-04 | Phase 3 - Single Axis | Install and verify home/limit switch | Project Owner | Not Started | Medium | 2 | 2026-08-19 | 2026-08-20 | 0% | P3-03 | Switch test
P3-GATE | Phase 3 - Single Axis | Milestone: single-axis motion gate | Project Owner | Not Started | High | 1 | 2026-08-21 | 2026-08-21 | 0% | P3-04 | Phase 3 checklist
P4-01 | Phase 4 - Three Axis | Bring up X, Y, and A motors and drivers | Project Owner | Not Started | High | 4 | 2026-08-24 | 2026-08-27 | 0% | P3-GATE | Bring-up notes
P4-02 | Phase 4 - Three Axis | Calibrate X/Y steps per mm and A motor degrees (M-03/M-04) | Project Owner | Not Started | High | 4 | 2026-08-28 | 2026-08-31 | 0% | P4-01 | M-03/M-04 results
P4-03 | Phase 4 - Three Axis | Verify 12:1 bed ratio and tune rates/acceleration (M-05) | Project Owner | Not Started | High | 3 | 2026-09-03 | 2026-09-05 | 0% | P4-02 | M-05 result
P4-04 | Phase 4 - Three Axis | Add homing and soft limits (M-07) | Project Owner | Not Started | High | 3 | 2026-09-08 | 2026-09-10 | 0% | P4-03 | M-07 result
P4-05 | Phase 4 - Three Axis | Run coordinated tests and converter sample without tool (M-06) | Project Owner | Not Started | High | 4 | 2026-09-11 | 2026-09-14 | 0% | P4-04 | M-06 result + G-code
P4-GATE | Phase 4 - Three Axis | Milestone: three-axis motion gate | Project Owner | Not Started | High | 1 | 2026-09-17 | 2026-09-17 | 0% | P4-05 | Phase 4 checklist
P5-01 | Phase 5 - Toolhead | Finalize toolhead controller placement | Project Owner | Not Started | High | 3 | 2026-09-21 | 2026-09-23 | 0% | P1-GATE | ADR update
P5-02 | Phase 5 - Toolhead | Verify actuator direction and safe travel (T-01) | Project Owner | Not Started | High | 3 | 2026-09-24 | 2026-09-26 | 0% | P5-01 | T-01 result
P5-03 | Phase 5 - Toolhead | Implement BOOT/LIFT/SEEK/HOLD/FAULT state machine | Codex | Not Started | High | 8 | 2026-09-28 | 2026-10-05 | 0% | P5-02 | Firmware commit
P5-04 | Phase 5 - Toolhead | Add travel, timeout, sensor, and force-limit faults | Codex | Not Started | High | 4 | 2026-10-06 | 2026-10-09 | 0% | P5-03 | Firmware tests
P5-05 | Phase 5 - Toolhead | Characterize backlash and implement contact seek (T-02) | Project Owner | Not Started | High | 4 | 2026-10-12 | 2026-10-15 | 0% | P5-04 | T-02 result
P5-06 | Phase 5 - Toolhead | Implement and tune force control (T-03) | Codex | Not Started | High | 7 | 2026-10-16 | 2026-10-22 | 0% | P5-05 | T-03 data + firmware
P5-07 | Phase 5 - Toolhead | Verify missing-paper, overforce, and disconnect faults (T-04 to T-06) | Project Owner | Not Started | High | 4 | 2026-10-26 | 2026-10-29 | 0% | P5-06 | T-04 to T-06 results
P5-GATE | Phase 5 - Toolhead | Milestone: toolhead bench-loop gate | Project Owner | Not Started | High | 1 | 2026-10-30 | 2026-10-30 | 0% | P5-07 | Phase 5 checklist
P6-01 | Phase 6 - Integration | Connect grblHAL M3/M5 to toolhead ENGAGE/LIFT | Project Owner | Not Started | High | 3 | 2026-11-02 | 2026-11-04 | 0% | P4-GATE,P5-GATE | Interface test
P6-02 | Phase 6 - Integration | Verify reset/E-stop safety and G4 dwell timing | Project Owner | Not Started | High | 3 | 2026-11-05 | 2026-11-07 | 0% | P6-01 | Safety test
P6-03 | Phase 6 - Integration | Check toolhead workload for lost steps or jitter | Project Owner | Not Started | High | 3 | 2026-11-10 | 2026-11-12 | 0% | P6-02 | Timing measurements
P6-04 | Phase 6 - Integration | Complete calibration and theta-heavy drawings | Project Owner | Not Started | High | 5 | 2026-11-13 | 2026-11-17 | 0% | P6-03 | Drawings + photos
P6-GATE | Phase 6 - Integration | Milestone: system integration gate | Project Owner | Not Started | High | 1 | 2026-11-20 | 2026-11-20 | 0% | P6-04 | Phase 6 checklist
P7-01 | Phase 7 - Validation | Measure calibration-pattern dimensions and execution time | Project Owner | Not Started | High | 4 | 2026-11-23 | 2026-11-26 | 0% | P6-GATE | Measurement tables
P7-02 | Phase 7 - Validation | Record force error during straight, curved, and rotating moves | Project Owner | Not Started | High | 4 | 2026-11-30 | 2026-12-03 | 0% | P7-01 | Force plots
P7-03 | Phase 7 - Validation | Photograph final wiring/mechanics and archive firmware/settings | Project Owner | Not Started | Medium | 3 | 2026-12-04 | 2026-12-06 | 0% | P7-02 | Photos + build archive
P7-04 | Phase 7 - Validation | Document results, failures, limitations, and future work | Codex | Not Started | High | 6 | 2026-12-09 | 2026-12-14 | 0% | P7-03 | Report draft
P7-05 | Phase 7 - Validation | Complete and export Systems Integration report | Codex | Not Started | High | 8 | 2026-12-17 | 2026-12-24 | 0% | P7-04 | Final report
P7-GATE | Phase 7 - Validation | Milestone: project validation and report complete | Project Owner | Not Started | High | 1 | 2026-12-29 | 2026-12-29 | 0% | P7-05 | Phase 7 checklist

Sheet: Lists
Status | Priority | Owner
Not Started | High | Project Owner
In Progress | Medium | Codex
Blocked | Low | Shared
Complete

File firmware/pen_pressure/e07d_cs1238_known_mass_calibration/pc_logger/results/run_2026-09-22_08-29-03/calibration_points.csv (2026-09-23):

number | mass_g | pass | calibration_load_direction | printing_force_relationship | capture_ms | sample_count | final_half_sample_count | raw_mean | raw_sigma | raw_file | included
1 | 2.5 | Loading | Downward weight on motor mount | Opposite: upward pen-tip reaction | 1000 | 651 | 325 | 262288.92615384614 | 239.67593652001355 | raw\point_001_0g_loading.csv | True
2 | 7.5 | Loading | Downward weight on motor mount | Opposite: upward pen-tip reaction | 1000 | 651 | 325 | 286509.17846153845 | 257.59617561202424 | raw\point_002_5g_loading.csv | True
3 | 12.5 | Loading | Downward weight on motor mount | Opposite: upward pen-tip reaction | 1000 | 650 | 325 | 312081.2369230769 | 253.38071541531866 | raw\point_003_10g_loading.csv | True
4 | 17.5 | Loading | Downward weight on motor mount | Opposite: upward pen-tip reaction | 1000 | 651 | 325 | 335965.7353846154 | 393.7140752571862 | raw\point_004_15g_loading.csv | True
5 | 22.5 | Loading | Downward weight on motor mount | Opposite: upward pen-tip reaction | 1000 | 651 | 325 | 365176.0123076923 | 256.64544804528845 | raw\point_005_20g_loading.csv | True
6 | 32.5 | Loading | Downward weight on motor mount | Opposite: upward pen-tip reaction | 1000 | 650 | 325 | 412387.3353846154 | 1203.614142672076 | raw\point_006_30g_loading.csv | True
7 | 42.5 | Loading | Downward weight on motor mount | Opposite: upward pen-tip reaction | 1000 | 651 | 325 | 459210.88615384616 | 311.0961404092227 | raw\point_007_40g_loading.csv | True
8 | 52.5 | Loading | Downward weight on motor mount | Opposite: upward pen-tip reaction | 1000 | 651 | 325 | 502663.75384615385 | 429.2041734247316 | raw\point_008_50g_loading.csv | True
9 | 72.5 | Loading | Downward weight on motor mount | Opposite: upward pen-tip reaction | 1000 | 650 | 325 | 609172.5784615384 | 403.7811335906954 | raw\point_009_70g_loading.csv | True
10 | 92.5 | Loading | Downward weight on motor mount | Opposite: upward pen-tip reaction | 1000 | 651 | 325 | 715868.1876923076 | 651.2111498543883 | raw\point_010_90g_loading.csv | True
11 | 72.5 | Unloading | Downward weight on motor mount | Opposite: upward pen-tip reaction | 1000 | 651 | 325 | 615485.1046153846 | 515.0797053872101 | raw\point_011_70g_unloading.csv | True
12 | 52.5 | Unloading | Downward weight on motor mount | Opposite: upward pen-tip reaction | 1000 | 650 | 325 | 515025.0830769231 | 618.4992873745614 | raw\point_012_50g_unloading.csv | True
13 | 42.5 | Unloading | Downward weight on motor mount | Opposite: upward pen-tip reaction | 1000 | 650 | 325 | 465881.0307692308 | 675.6930383910859 | raw\point_013_40g_unloading.csv | True
14 | 32.5 | Unloading | Downward weight on motor mount | Opposite: upward pen-tip reaction | 1000 | 651 | 325 | 417847.3846153846 | 392.2617372782418 | raw\point_014_30g_unloading.csv | True
15 | 22.5 | Unloading | Downward weight on motor mount | Opposite: upward pen-tip reaction | 1000 | 651 | 325 | 367280.47076923074 | 390.9471456399492 | raw\point_015_20g_unloading.csv | True
16 | 17.5 | Unloading | Downward weight on motor mount | Opposite: upward pen-tip reaction | 1000 | 651 | 325 | 341371.95692307694 | 564.7571497062952 | raw\point_016_15g_unloading.csv | True
17 | 12.5 | Unloading | Downward weight on motor mount | Opposite: upward pen-tip reaction | 1000 | 650 | 325 | 313041.28615384613 | 494.13958285766336 | raw\point_017_10g_unloading.csv | True
18 | 7.5 | Unloading | Downward weight on motor mount | Opposite: upward pen-tip reaction | 1000 | 650 | 325 | 290782.56 | 359.80197151723934 | raw\point_018_5g_unloading.csv | True
19 | 2.5 | Unloading | Downward weight on motor mount | Opposite: upward pen-tip reaction | 1000 | 651 | 325 | 264849.19384615385 | 318.0061769486794 | raw\point_019_0g_unloading.csv | True

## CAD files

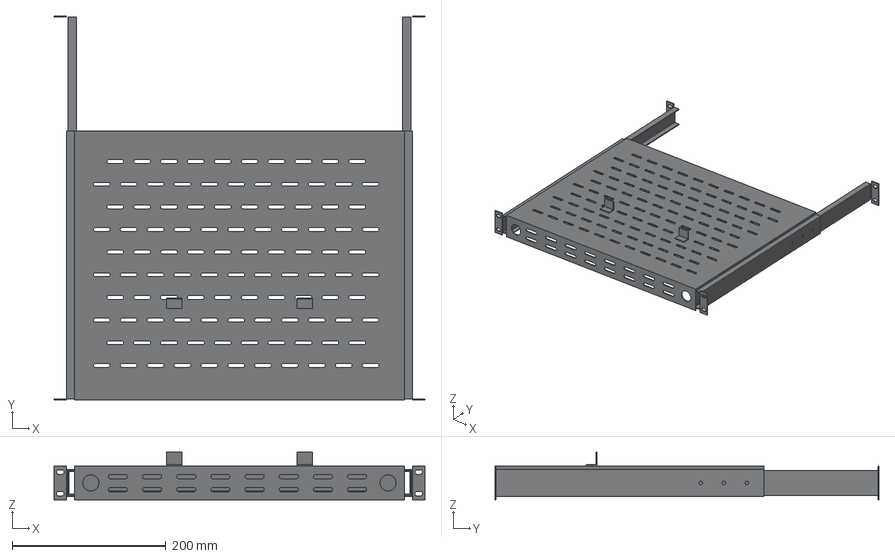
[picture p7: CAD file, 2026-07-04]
docs/hardware/cad/tecmojo-14130201-500mm.step
482.6 x 500.0 x 62.5 mm
sliding_shelf
left_slide_member
right_slide_member
left_front_support
right_front_support
left_rear_support
right_rear_support
left_front_ear
right_front_ear
left_rear_ear
right_rear_ear
left_anti_slip_stop
right_anti_slip_stop

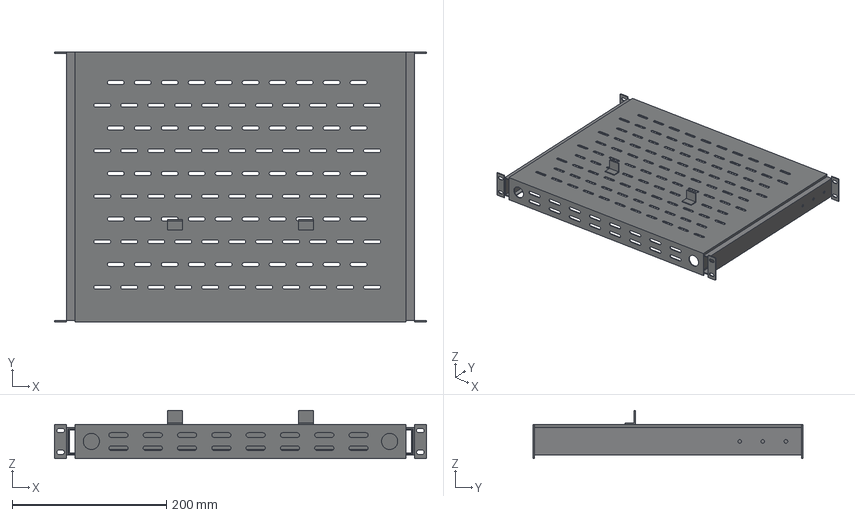
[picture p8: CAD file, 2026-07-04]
docs/hardware/cad/tecmojo-14130201-350mm.step
482.6 x 350.0 x 62.5 mm
sliding_shelf
left_slide_member
right_slide_member
left_front_support
right_front_support
left_rear_support
right_rear_support
left_front_ear
right_front_ear
left_rear_ear
right_rear_ear
left_anti_slip_stop
right_anti_slip_stop

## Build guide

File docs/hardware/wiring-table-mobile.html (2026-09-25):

# Master Wiring Table

Mobile card view generated from WIRING_TABLE.md. The Markdown file remains authoritative. Re-run the generator after wiring changes.

No connections match that filter.

## Status definitions

### TBD

Status

TBD

Meaning

Proposed or not yet assigned; do not connect

### documented

Status

documented

Meaning

Supported by a manufacturer schematic/manual but not checked on this machine

### continuity-checked

Status

continuity-checked

Meaning

Wiring has been checked unpowered with a meter

### bench-verified

Status

bench-verified

Meaning

Connection has passed a powered subsystem test

### machine-verified

Status

machine-verified

Meaning

Connection has passed an integrated machine test

### rejected

Status

rejected

Meaning

Connection was tested or reviewed and must not be used

## MEISHILE S-120-12 terminal map

### 1

Terminal

1

Marking

L

Function

AC line/live input

Verification status

documented

Evidence/notes

Physical unit observation; QR-linked manual archived in references/

### 2

Terminal

2

Marking

N

Function

AC neutral input

Verification status

documented

Evidence/notes

Physical unit observation

### 3

Terminal

3

Marking

Protective-earth symbol

Function

Protective earth/chassis safety ground

Verification status

documented

Evidence/notes

Physical unit observation; continuity to chassis must be tested before power

### 4

Terminal

4

Marking

-V

Function

DC output negative

Verification status

documented

Evidence/notes

One of two parallel negative output terminals

### 5

Terminal

5

Marking

-V

Function

DC output negative

Verification status

documented

Evidence/notes

One of two parallel negative output terminals

### 6

Terminal

6

Marking

+V

Function

DC output positive

Verification status

documented

Evidence/notes

One of two parallel positive output terminals

### 7

Terminal

7

Marking

+V

Function

DC output positive

Verification status

documented

Evidence/notes

One of two parallel positive output terminals

### Adjacent to 7

Terminal

Adjacent to 7

Marking

+V ADJ

Function

Output-voltage adjustment screw

Verification status

documented

Evidence/notes

Measure with no load before connecting electronics; adjustment is not a current control

## MEISHILE S-120-12 terminal map

### PWR-001

From device

AC mains

From terminal

Hot

To device

MEISHILE S-120-12

To terminal

Terminal 1 L

Signal/rail

AC line/live

Expected level

100-240 VAC listing range

Wire

Red, verified

Protection

Enclosure, switch, line fuse, strain relief TBD

Status

verified — terminal identity only

Evidence/notes

Owner verified red is landed at the printed L terminal. Enclosure/protection and powered checks remain open.

### PWR-001N

From device

AC mains

From terminal

Neutral

To device

MEISHILE S-120-12

To terminal

Terminal 2 N

Signal/rail

AC neutral

Expected level

100-240 VAC listing range

Wire

Blue, verified

Protection

Same protected inlet as PWR-001

Status

verified — terminal identity only

Evidence/notes

Owner verified blue is landed at the printed N terminal. Keep neutral distinct from protective earth.

### PWR-001E

From device

Protective earth

From terminal

PE

To device

MEISHILE S-120-12

To terminal

Terminal 3 earth

Signal/rail

Protective earth

Expected level

Safety bonding conductor

Wire

Green, verified

Protection

X cable shield/drain landed here; supply PE/chassis path passed

Status

verified — terminal identity/landing/PE path

Evidence/notes

Owner verified the green wall-earth conductor and green X sheath/drain are landed at the protective-earth symbol terminal, and the PE terminal-to-supply-chassis path passes. The powder-coated machine structure is not used as the protective-earth reference. This is never -V, L, or N.

### PWR-002

From device

HCDC HD064RT

From terminal

OUT1 fused pair

To device

RP23CNC

To terminal

Main power input TBD

Signal/rail

Controller/control-input supply

Expected level

12 VDC nominal, always on during E-stop

Wire

TBD

Protection

OUT1/FCTRL, 2 A selected; confirm fitted marking

Status

planned

Evidence/notes

Owner allocated RP23CNC to OUT1. Controller remains powered when SW1 is pressed; final terminal allocation and E-19/current measurement remain required.

### PWR-003

From device

HCDC HD064RT

From terminal

OUT6 +

To device

X TB6600

To terminal

VCC/DC+ TBD

Signal/rail

X stepper power

Expected level

12 VDC nominal; E-stop does not remove this power

Wire

20 AWG, owner-reported

Protection

OUT6 branch fuse, 3 A selected; confirm fitted marking

Status

planned — wired, unverified

Evidence/notes

Owner reports the positive conductor is physically landed from OUT6; owner selects a 3 A branch fuse. Confirm exact driver terminal, polarity, fitted fuse marking, and continuity before power. Do not bypass the HD064RT branch fuse.

### PWR-004

From device

HCDC HD064RT

From terminal

OUT6 -

To device

X TB6600

To terminal

GND/DC- TBD

Signal/rail

X stepper return

Expected level

0 VDC

Wire

20 AWG, owner-reported

Protection

Paired with PWR-003

Status

planned — wired, unverified

Evidence/notes

Owner reports the return conductor is physically landed; confirm exact driver terminal and continuity with power removed.

### PWR-005

From device

HCDC HD064RT

From terminal

OUT7 +

To device

Y TB6600

To terminal

VCC/DC+ TBD

Signal/rail

Y stepper power

Expected level

12 VDC nominal; E-stop does not remove this power

Wire

20 AWG, owner-reported

Protection

OUT7 branch fuse, 3 A selected; confirm fitted marking

Status

planned — wired, unverified

Evidence/notes

Owner reports the positive conductor is physically landed from OUT7; owner selects a 3 A branch fuse. Confirm exact driver terminal, polarity, fitted fuse marking, and continuity before power. Do not bypass the HD064RT branch fuse.

### PWR-006

From device

HCDC HD064RT

From terminal

OUT7 -

To device

Y TB6600

To terminal

GND/DC- TBD

Signal/rail

Y stepper return

Expected level

0 VDC

Wire

20 AWG, owner-reported

Protection

Paired with PWR-005

Status

planned — wired, unverified

Evidence/notes

Owner reports the return conductor is physically landed; confirm exact driver terminal and continuity with power removed.

### PWR-007

From device

HCDC HD064RT

From terminal

OUT8 +

To device

A TB6600

To terminal

VCC/DC+ TBD

Signal/rail

A stepper power

Expected level

12 VDC nominal; E-stop does not remove this power

Wire

20 AWG, owner-reported

Protection

OUT8 branch fuse, 3 A selected; confirm fitted marking

Status

planned — wired, unverified

Evidence/notes

Owner reports the positive conductor is physically landed from OUT8; owner selects a 3 A branch fuse. Confirm exact driver terminal, polarity, fitted fuse marking, and continuity before power. Do not bypass the HD064RT branch fuse.

### PWR-008

From device

HCDC HD064RT

From terminal

OUT8 -

To device

A TB6600

To terminal

GND/DC- TBD

Signal/rail

A stepper return

Expected level

0 VDC

Wire

20 AWG, owner-reported

Protection

Paired with PWR-007

Status

planned — wired, unverified

Evidence/notes

Owner reports the return conductor is physically landed; confirm exact driver terminal and continuity with power removed.

### PWR-009A

From device

HCDC HD064RT

From terminal

OUT4 +

To device

Pololu D36V50F6

To terminal

VIN

Signal/rail

Toolhead 6 V regulator input

Expected level

12 VDC nominal; E-stop does not remove this power; regulator accepts 6.5-50 V input

Wire

TBD

Protection

OUT4 branch fuse, 3 A intended; confirm fitted marking

Status

verified

Evidence/notes

E-14 passed 2026-09-08; owner reported correct polarity and constant 6.05 V regulator output. Branch-fuse marking/current characterization remains E-15.

### PWR-009B

From device

HCDC HD064RT

From terminal

OUT4 -

To device

Pololu D36V50F6

To terminal

GND

Signal/rail

Toolhead 6 V regulator return

Expected level

0 VDC

Wire

TBD

Protection

Paired with PWR-009A

Status

verified

Evidence/notes

E-14 passed; return path supports the 6.05 V output measurement.

### PWR-009

From device

Pololu D36V50F6

From terminal

VOUT via 2-pin toolhead JST

To device

DRV8833

To terminal

VCC/VM TBD

Signal/rail

Actuator motor power

Expected level

Fixed 6.0 V output

Wire

20 AWG red/black twisted pair TBD

Protection

Output fuse/capacitance TBD

Status

verified

Evidence/notes

E-14 passed 2026-09-08 with constant 6.05 V reported. E-15 remains the loaded ripple/current/temperature characterization.

### PWR-010

From device

Pololu D36V50F6

From terminal

GND via 2-pin toolhead JST

To device

DRV8833

To terminal

GND TBD

Signal/rail

Actuator return

Expected level

0 V

Wire

20 AWG black return in the same twisted pair TBD

Protection

Same branch as PWR-009

Status

bench-verified

Evidence/notes

Continuity passed and the DRV8833 received the correct bench-powered rail. Do not use the JST as a logic-only connector: this ground is the driver power return and local logic reference.

### PWR-013

From device

SparkFun Pro Micro RP2350

From terminal

3V3

To device

CS1238

To terminal

VCC

Signal/rail

Load-cell ADC power

Expected level

3.3 V only after received-board inspection

Wire

Short local conductor TBD

Protection

Local decoupling TBD

Status

planned

Evidence/notes

The Pro Micro is the sole CS1238 owner; verify actual breakout supply/reference behavior in E-07C/E-07D.

### PWR-014

From device

SparkFun Pro Micro RP2350

From terminal

GND

To device

CS1238

To terminal

GND

Signal/rail

Load-cell ADC return

Expected level

0 V

Wire

Short local conductor TBD

Protection

Same local toolhead reference

Status

planned

Evidence/notes

Keep the ADC close to the load cell; no Pico or INA101 path remains.

### PWR-015

From device

SparkFun Pro Micro RP2350

From terminal

Qwiic 3V3/GND

To device

TMAG5273 Qwiic

To terminal

Qwiic 3V3/GND

Signal/rail

Hall sensor power

Expected level

3.3 V Qwiic

Wire

Qwiic cable TBD

Protection

Qwiic pullups on controller side

Status

documented

Evidence/notes

SparkFun documents Pro Micro RP2350 Qwiic on GPIO16/17 with 3.3 V pullups

## Motion control signals

### MOT-001

From device

RP23CNC

From terminal

X Stp

To device

X TB6600

To terminal

PUL+

Signal

X step pulse

Expected level/polarity

5 V pulse activity during commanded motion

Wire

24 AWG blue

Status

bench-verified

Evidence/notes

F-03 and E-03 passed; installed-driver signal response recorded 2026-09-05.

### MOT-002

From device

RP23CNC

From terminal

X Dir

To device

X TB6600

To terminal

DIR+

Signal

X direction

Expected level/polarity

0 V positive, 5 V negative direction

Wire

24 AWG white

Status

bench-verified

Evidence/notes

F-03 and E-03 passed; installed-driver signal response recorded 2026-09-05.

### MOT-003

From device

RP23CNC

From terminal

X En

To device

X TB6600

To terminal

ENA+

Signal

X enable

Expected level/polarity

Active-low: 5 V idle, 0 V moving

Wire

24 AWG yellow

Status

bench-verified

Evidence/notes

F-03 and E-03 passed; installed-driver signal response recorded 2026-09-05.

### MOT-004

From device

RP23CNC

From terminal

Y Stp / Dir / En

To device

Y TB6600

To terminal

PUL+ / DIR+ / ENA+

Signal

Y step, direction, enable

Expected level/polarity

Same F-03 logic as X

Wire

24 AWG blue / white / yellow

Status

bench-verified

Evidence/notes

Owner reports the installed-driver response matches X/A; E-03 recorded 2026-09-05.

### MOT-005

From device

RP23CNC

From terminal

A Stp / Dir / En

To device

A TB6600

To terminal

PUL+ / DIR+ / ENA+

Signal

A step, direction, enable

Expected level/polarity

Same F-03 logic as X

Wire

24 AWG blue / white / yellow

Status

bench-verified

Evidence/notes

A-axis installed-driver response passed 2026-09-05; X/Y reported matching.

### MOT-006

From device

RP23CNC

From terminal

X G

To device

X TB6600

To terminal

PUL-, DIR-, ENA- via common block

Signal

X signal return

Expected level/polarity

Axis-local common reference

Wire

24 AWG black; three common-block jumpers

Status

bench-verified

Evidence/notes

Common return continuity and E-03 signal response passed; do not use isolated-input ground.

### MOT-007

From device

RP23CNC

From terminal

Y G

To device

Y TB6600

To terminal

PUL-, DIR-, ENA- via common block

Signal

Y signal return

Expected level/polarity

Axis-local common reference

Wire

24 AWG black; three common-block jumpers

Status

bench-verified

Evidence/notes

Common return continuity and E-03 signal response passed; do not use isolated-input ground.

### MOT-008

From device

RP23CNC

From terminal

A G

To device

A TB6600

To terminal

PUL-, DIR-, ENA- via common block

Signal

A signal return

Expected level/polarity

Axis-local common reference

Wire

24 AWG black; three common-block jumpers

Status

bench-verified

Evidence/notes

Common return continuity and E-03 signal response passed; do not use isolated-input ground.

## Stepper motor phases

### XPH-001

From device

X TB6600

From terminal

A+

To device

X motor

To terminal

A+ lead

Signal

Phase A+

Wire color

Planned shielded motor run; black lead

Status

partial

Evidence/notes

Owner hand-turn generated-voltage test, 2026-08-19: black/green is one coil; retain lead order pending M-01 direction check and shielded-run installation.

### XPH-002

From device

X TB6600

From terminal

A-

To device

X motor

To terminal

A- lead

Signal

Phase A-

Wire color

Planned shielded motor run; green lead

Status

partial

Evidence/notes

Owner hand-turn generated-voltage test, 2026-08-19: black/green is one coil.

### XPH-003

From device

X TB6600

From terminal

B+

To device

X motor

To terminal

B+ lead

Signal

Phase B+

Wire color

Planned shielded motor run; red -> motor red

Status

partial

Evidence/notes

Owner correction, 2026-08-23: X B+ is red; retain lead order pending M-01 direction check and shielded-run installation.

### XPH-004

From device

X TB6600

From terminal

B-

To device

X motor

To terminal

B- lead

Signal

Phase B-

Wire color

Planned shielded motor run; white -> motor blue

Status

partial

Evidence/notes

Owner correction, 2026-08-23: X B- is white; white is the cable-side continuation of the motor's blue B- lead.

### XSH-001

From device

X motor cable shield/drain

From terminal

Green sheath/drain wire at TB6600 end

To device

MEISHILE S-120-12 protective-earth terminal

To terminal

Earth symbol / PE

Signal

Cable shield bond

Wire color

Green, verified

Status

verified — PE path and isolation passed

Evidence/notes

Owner verified this wire is landed at the same protective-earth terminal as the wall's earth conductor; the PE terminal-to-supply-chassis path passes and the sheath has no continuity to DC -V or any motor-phase conductor. Keep the shield insulated at the motor end.

### YPH-001

From device

Y TB6600

From terminal

A+

To device

Y motor

To terminal

A+ lead

Signal

Phase A+

Wire color

Unshielded motor lead black

Status

continuity-checked

Evidence/notes

Owner report, 2026-08-23: black/green is one coil; final driver direction remains M-01/M-03.

### YPH-002

From device

Y TB6600

From terminal

A-

To device

Y motor

To terminal

A- lead

Signal

Phase A-

Wire color

Unshielded motor lead green

Status

continuity-checked

Evidence/notes

Owner report, 2026-08-23: black/green is one coil.

### YPH-003

From device

Y TB6600

From terminal

B+

To device

Y motor

To terminal

B+ lead

Signal

Phase B+

Wire color

Unshielded motor lead red

Status

continuity-checked

Evidence/notes

Owner report, 2026-08-23: red/blue is one coil; final driver direction remains M-01/M-03.

### YPH-004

From device

Y TB6600

From terminal

B-

To device

Y motor

To terminal

B- lead

Signal

Phase B-

Wire color

Unshielded motor lead blue

Status

continuity-checked

Evidence/notes

Owner report, 2026-08-23: red/blue is one coil.

### APH-001

From device

A TB6600

From terminal

A+

To device

A motor

To terminal

A+ lead

Signal

Phase A+

Wire color

Supplied unshielded 24 AWG motor lead black

Status

continuity-checked

Evidence/notes

Owner hand-turn generated-voltage test, 2026-08-19: black/green is one coil; retain lead order pending M-01 direction check.

### APH-002

From device

A TB6600

From terminal

A-

To device

A motor

To terminal

A- lead

Signal

Phase A-

Wire color

Supplied unshielded 24 AWG motor lead green

Status

continuity-checked

Evidence/notes

Owner hand-turn generated-voltage test, 2026-08-19: black/green is one coil.

### APH-003

From device

A TB6600

From terminal

B+

To device

A motor

To terminal

B+ lead

Signal

Phase B+

Wire color

Supplied unshielded 24 AWG motor lead red

Status

continuity-checked

Evidence/notes

Owner hand-turn generated-voltage test, 2026-08-19: red/blue is one coil; retain lead order pending M-01 direction check.

### APH-004

From device

A TB6600

From terminal

B-

To device

A motor

To terminal

B- lead

Signal

Phase B-

Wire color

Supplied unshielded 24 AWG motor lead blue

Status

continuity-checked

Evidence/notes

Owner hand-turn generated-voltage test, 2026-08-19: red/blue is one coil.

## Limits, controls, and safety

### SAF-001

From device

X HiLetgo KW12-3 limit switch

From terminal

COM (yellow) and NC (green)

To device

RP23CNC

To terminal

LIM X: SIG and GND

Signal

X home/limit

Expected behavior

NC released/healthy, opens when tripped or wire breaks; X is inactive released and reports active only while pressed with $5=0

Wire

Two-conductor limit lead

Status

partial — wired and live-report tested

Evidence/notes

COM to SIG; NC to GND. Owner meter-verified COM–NC continuity with lever released and open circuit pressed. ioSender live indicator changed only for X while its switch was pressed (2026-08-22). Hard-limit alarm test remains open.

### SAF-002

From device

Y HiLetgo KW12-3 limit switch

From terminal

COM (yellow) and NC (green)

To device

RP23CNC

To terminal

LIM Y: SIG and GND

Signal

Y home/limit

Expected behavior

NC released/healthy, opens when tripped or wire breaks; Y is inactive released and reports active only while pressed with $5=0

Wire

Two-conductor limit lead

Status

partial — wired and live-report tested

Evidence/notes

COM to SIG; NC to GND. Owner meter-verified COM–NC continuity with lever released and open circuit pressed. ioSender live indicator changed only for Y while its switch was pressed (2026-08-22). Hard-limit alarm test remains open.

### SAF-003

From device

A index sensor

From terminal

TBD

To device

RP23CNC

To terminal

A limit/probe input TBD

Signal

Bed index/home

Expected behavior

Polarity TBD

Wire

Shielded/twisted TBD

Status

TBD

Evidence/notes

Sensor selection pending

### SAF-004

From device

SW1 mxuteuk HB2-BS544 E-stop, NC-A

From terminal

Upper 1/NC/2 contact block in supplied rear-switch photo; use its terminal 1 and terminal 2

To device

RP23CNC

To terminal

ESTOP: SIG and GND (rightmost pair in the Grbl Control Inputs group, after FD HOLD)

Signal

Immediate grblHAL Halt

Expected behavior

NC released/healthy, open when pressed; NC input configuration $14=6

Wire

Low-current protected control wire TBD

Status

verified

Evidence/notes

Run one wire from either NC-A terminal to SIG and the other to GND; the two assignments are interchangeable. Never mix terminals between NC-A and NC-B. On 2026-09-08, power-off meter test gave continuity/beep released and open/no beep pressed; $14=6 plus press produced ioSender ALARM:10; twist-release → Reset → Unlock returned it to IDLE with no motion reported. This controller-signal stop leaves motor/tool 12 V powered; see ESTOP_TOPOLOGY.md.

### SAF-005

From device

SW1 mxuteuk HB2-BS544 E-stop, NC-B

From terminal

Lower independent 1/NC/2 contact block in supplied rear-switch photo

To device

None

To terminal

Both terminals individually insulated

Signal

Unused

Expected behavior

No electrical connection

Wire

None

Status

planned

Evidence/notes

K1 is not part of this project. Do not connect NC-B to power, ground, or NC-A.

### SAF-006

From device

MEISHILE S-120-12

From terminal

+V through FMAIN

To device

HCDC HD064RT

To terminal

DC INPUT +

Signal

12 V motor/tool feed

Expected behavior

12 V while the main power is on; E-stop does not remove this power

Wire

Protected 12 V positive TBD

Status

partial

Evidence/notes

On 2026-08-20, the powered HD064RT input and one output pair each measured 12.05 VDC and polarity matched the block markings. On 2026-08-21, the mains-input and DC-output conductors were rerouted not to overlap. FMAIN maximum 10 A; do not bypass it. PE bonding, adjustment range, fitted fuse, and loaded behavior remain open; see E-11 lab note.

### SAF-007

From device

HCDC HD064RT

From terminal

OUT6 / fused pair

To device

X TB6600

To terminal

12 V input

Signal

X motor power

Expected behavior

Remains powered when SW1 is pressed

Wire

20 AWG, fuse 3 A selected

Status

planned

Evidence/notes

Owner reports branch wired; confirm fitted marking/current before power.

### SAF-008

From device

HCDC HD064RT

From terminal

OUT7 / fused pair

To device

Y TB6600

To terminal

12 V input

Signal

Y motor power

Expected behavior

Remains powered when SW1 is pressed

Wire

20 AWG, fuse 3 A selected

Status

planned

Evidence/notes

Owner reports branch wired; confirm fitted marking/current before power.

### SAF-009

From device

HCDC HD064RT

From terminal

OUT8 / fused pair

To device

A TB6600

To terminal

12 V input

Signal

A motor power

Expected behavior

Remains powered when SW1 is pressed

Wire

20 AWG, fuse 3 A selected

Status

planned

Evidence/notes

Owner reports branch wired; confirm fitted marking/current before power.

### SAF-010

From device

HCDC HD064RT

From terminal

OUT4 / fused pair

To device

Pololu D36V50F6

To terminal

VIN/GND

Signal

Toolhead motor supply source

Expected behavior

Remains powered when SW1 is pressed

Wire

Branch wire/fuse TBD

Status

planned

Evidence/notes

Owner intends 3 A; confirm fitted marking and characterize E-15

### SAF-011

From device

HCDC HD064RT

From terminal

OUT1 / fused pair

To device

RP23CNC

To terminal

12 V main input TBD

Signal

Controller/control-input supply

Expected behavior

Remains powered when SW1 is pressed

Wire

Branch wire/fuse TBD

Status

planned

Evidence/notes

2 A selected; confirm fitted marking, terminal labels, and E-19 behavior before power

## Magnetic bed registration interface

### MAG-001

From device

SparkFun TMAG5273 Qwiic

From terminal

Qwiic SDA/SCL/3V3/GND

To device

SparkFun Pro Micro RP2350

To terminal

Qwiic GPIO16/GPIO17/3V3/GND

Signal

3D Hall readings

Expected behavior

3.3 V I2C; stable magnetic vector or magnitude readings

Wire

Qwiic cable TBD

Status

bench-verified

Evidence/notes

E-09 passed after correcting the signal pair: GP16 is SDA and GP17 is SCL. Far/near/return magnitudes were 0.24/7.51/7.44 mT; initial threshold guidance 3.5 mT with 1.0 mT hysteresis.

### MAG-002

From device

SparkFun Pro Micro RP2350

From terminal

USB device TBD

To device

Host PC

To terminal

USB TBD

Signal

Service telemetry

Expected behavior

Reports pressure state, magnetic state/vector, and faults for commissioning; it does not send numeric centroids to RP23CNC

Wire

USB cable TBD

Status

source implemented; installed test TBD

Evidence/notes

P100 owns position capture and centroid arithmetic.

### MAG-003

From device

SparkFun Pro Micro RP2350

From terminal

GP27 through PC817C U3

To device

RP23CNC

To terminal

PROBE SIG

Signal

Phase 1 readiness ACK; phase 2 thresholded magnetic state

Expected behavior

Isolated switch-like low-side return to the controller probe input; never drive a controller input high

Wire

Existing blue routed control conductor

Status

machine-verified, F-08 partial

Evidence/notes

On 2026-09-10, after direct PRB polarity/G38 checks, blue A_HOME moved from LIMA SIG to PROBE SIG with power off. J1.5 CTRL_GND was confirmed common with controller PROBE GND. With $6=1, M65 P0/READY_ACK made P red and M64 P0/release made P blank. In scan, real TMAG detected=0 -> 1 -> 0 matched P blank -> red -> blank; real-magnet A G38.3/.5 both returned :1. On 2026-09-11, P105 held the asserted path at 173.4 mV and G65 P100 Q1 passed its automatic PRB assert/release checks. Q2–Q4 and coordinate commissioning remain open.

### MAG-003A

From device

RP23CNC

From terminal

Aux 0 digital output

To device

PC817C module U2 LED cathode

To terminal

AUX0 / pin 2

Signal

Two-phase magnetic arm; end-of-print full-retract request during normal print

Expected behavior

Installed path is active-low: M65 P0 requests readiness, scan, or full retract, and M64 P0 releases/disarms; M65 -> M64 -> M65 enters scan

Wire

Existing routed control conductor

Status

machine-verified, F-08 partial

Evidence/notes

On 2026-09-10, J1.4 measured 9.33 V released and 0.15 mV asserted relative to J1.5 CTRL_GND; the installed diagnostic observed DISARMED → READY_ACK → WAIT_REARM → SCAN_ACTIVE → DISARMED, followed by controller-visible PRB/G38 proof.

### MAG-003B

From device

PC817C module U2 collector

From terminal

GP28 / pullup node

To device

SparkFun Pro Micro RP2350

To terminal

GP28 / A2

Signal

Isolated two-phase arm input

Expected behavior

Local 3.3 V pullup through R4; U2 on pulls GP28 low

Wire

Existing routed control conductor

Status

harness re-test required

Evidence/notes

Core 1 owns the handshake; unsafe state or timeout suppresses GP27.

### MAG-004

From device

Center bed magnet

From terminal

Embedded bed center

To device

TMAG5273 scan path

To terminal

Sensor over bed

Signal

Bed-center reference

Expected behavior

Saturated or thresholded footprint centered on bed rotation axis

Wire

Mechanical placement

Status

TBD

Evidence/notes

Cylindrical magnet; diameter, grade, polarity, and depth TBD

### MAG-005

From device

Outer bed magnet

From terminal

Embedded near 8.9 in radius

To device

TMAG5273 scan path

To terminal

Sensor over bed

Signal

Theta/A index reference

Expected behavior

Saturated or thresholded footprint centered on angular index mark

Wire

Mechanical placement

Status

TBD

Evidence/notes

Cylindrical magnet; final measured radius and angular reference TBD

## Toolhead control and sensors

### TH-001A

From device

RP23CNC

From terminal

Spindle group ENA

To device

PC817C module U1 LED cathode

To terminal

ENA / pin 2

Signal

M3/M5 command into isolation module

Expected level/polarity

U1 LED lights only when ENA sinks current from controller +5V through R1. The controller ENA is active-high by default, so the controller sets $16=1 (invert spindle enable): M3 pulls ENA low (opto on, engage) and M5 leaves it high (opto off, lift)

Wire

Shielded/twisted TBD

Status

verified — F-05, 2026-09-23

Evidence/notes

See hardware/pc817-interface/pc817-interface.sch; RP23U5XBB manual identifies spindle ENA. F-05 confirmed M3 = pen down and M5 = pen up, with pen-up fail-safe when the controller is unpowered. ENA meter levels at idle/M3/M5 are not yet recorded.

### TH-001A-RT

From device

RP23CNC

From terminal

5V, spindle ENA, Aux 0, control GND, and PROBE SIG

To device

Toolhead PC817C module J1.1, J1.2, J1.4, J1.5, and J1.6 respectively

To terminal

Controller-side moving harness

Signal

Isolated tool command, HOME_ARM, and reverse A_HOME/probe path

Expected level/polarity

Controller and toolhead ground domains remain galvanically isolated; controller PROBE GND is continuous with J1.5 CTRL_GND on this installed board

Wire

Five routed control conductors through drag chain

Status

partial energized evidence

Evidence/notes

J1.1 CTRL_5V, J1.2 ENA, J1.4 AUX0, and J1.5 CTRL_GND were reported wired on 2026-08-23. On 2026-09-10, blue J1.6 moved from LIMA SIG to PROBE SIG after direct PRB and real GP27/U3 path tests passed. The PRB state and real-magnet A-axis G38 capture/release are verified. M3/M5 polarity is verified (F-05, 2026-09-23: $16=1, M3 down / M5 up); the macro, F-05A, and production-use commissioning remain open. J1.3 remains unused.

### TH-001B

From device

PC817C module U1 collector

From terminal

GP29 / pullup node

To device

SparkFun Pro Micro RP2350

To terminal

GP29 / A3

Signal

M3/M5 isolated output to Pro Micro

Expected level/polarity

Local 3.3 V pullup through R3; U1 on pulls GP29 low

Wire

Shielded/twisted TBD

Status

harness re-test required

Evidence/notes

U1 passed the simulated test on prior GP8 wiring; repeat it on GP29. Actual RP23CNC ENA behavior remains F-05.

### TH-002

From device

SparkFun Pro Micro RP2350

From terminal

GP4

To device

DRV8833

To terminal

IN1

Signal

Motor direction/PWM

Expected level/polarity

3.3 V logic PWM

Wire

Short local conductor

Status

continuity-checked

Evidence/notes

Continuity passed 2026-08-12; powered direction/PWM behavior remains T-01. Module label may read AIN1 on other DRV8833 boards.

### TH-003

From device

SparkFun Pro Micro RP2350

From terminal

GP5

To device

DRV8833

To terminal

IN2

Signal

Motor direction/PWM

Expected level/polarity

3.3 V logic PWM

Wire

Short local conductor

Status

continuity-checked

Evidence/notes

Continuity passed 2026-08-12; powered direction/PWM behavior remains T-01. Module label may read AIN2 on other DRV8833 boards.

### TH-003A

From device

SparkFun Pro Micro RP2350

From terminal

GP6

To device

DRV8833

To terminal

EEP / low-true sleep input

Signal

Driver enable/sleep

Expected level/polarity

Drive HIGH to enable, LOW to sleep

Wire

Short local conductor

Status

continuity-checked; function re-test pending

Evidence/notes

The owner confirmed the installed module's pin-1 silkscreen is SLEEP/EEP. Keep the installed GP6→EEP wire; firmware must drive it.

### TH-003B

From device

DRV8833

From terminal

ULT / low-true protection-fault output

To device

SparkFun Pro Micro RP2350

To terminal

GP7

Signal

Driver fault input

Expected level/polarity

Open-drain-style active-low fault; firmware uses INPUT_PULLUP

Wire

Short local conductor

Status

continuity-checked; function re-test pending

Evidence/notes

The owner confirmed the installed module's pin-6 silkscreen is FAULT/ULT. Keep the installed ULT→GP7 wire; firmware must read it.

### TH-003C

From device

SparkFun Pro Micro RP2350

From terminal

GP4, GP5, GP6, GP7

To device

DRV8833

To terminal

logic connector

Signal

One 1×4 direct-header harness

Expected level/polarity

Consecutive left-side GPIO run; GND is supplied by the separate DRV8833 power connector

Wire

Short local harness

Status

continuity-checked

Evidence/notes

Installed harness is GP4→IN1, GP5→IN2, GP6→EEP/sleep, and ULT/fault→GP7. The earlier opposite EEP/ULT role record is superseded by the installed-board label confirmation.

### TH-003D

From device

SparkFun Pro Micro RP2350

From terminal

GND, RST NC, 3V3, GP29, GP28, GP27

To device

PC817C module

To terminal

J2.4, NC, J2.2, J2.1, J2.3, J2.6

Signal

One 1×6 direct-header harness

Expected level/polarity

Consecutive right-side Pro Micro run; RST remains unconnected and CTRL_GND is excluded

Wire

1×6 JST-compatible harness

Status

continuity-checked

Evidence/notes

All currently wired Pro Micro logic pins passed continuity 2026-08-12. RST remains intentionally unconnected; repeat functional E-18 testing after repinning.

### TH-006

From device

uxcell 300 g load cell

From terminal

Red (EXC+)

To device

CS1238

To terminal

E+

Signal

Bridge excitation positive

Expected level/polarity

Manufacturer wire/function mapping

Wire

Short local conductor TBD

Status

planned

Evidence/notes

Red EXC+, black EXC-, green SEN+, white SEN-; verify received CS1238 labels before energizing. Calibrate with precision masses through the installed pen force path.

### TH-007

From device

uxcell 300 g load cell

From terminal

Black (EXC-)

To device

CS1238

To terminal

E-

Signal

Bridge excitation negative

Expected level/polarity

Manufacturer wire/function mapping

Wire

Short local conductor TBD

Status

planned

Evidence/notes

E-07D known-mass calibration required.

### TH-008

From device

uxcell 300 g load cell

From terminal

Green (SEN+)

To device

CS1238

To terminal

A+

Signal

Bridge signal positive

Expected level/polarity

Manufacturer wire/function mapping

Wire

Short local conductor TBD

Status

planned

Evidence/notes

E-07D known-mass calibration required.

### TH-009

From device

uxcell 300 g load cell

From terminal

White (SEN-)

To device

CS1238

To terminal

A-

Signal

Bridge signal negative

Expected level/polarity

Manufacturer wire/function mapping

Wire

Short local conductor TBD

Status

planned

Evidence/notes

E-07D known-mass calibration required.

### TH-010

From device

CS1238

From terminal

DT/DRDY

To device

SparkFun Pro Micro RP2350

To terminal

GP0

Signal

Load-cell data

Expected level/polarity

3.3 V logic

Wire

Short local conductor

Status

planned

Evidence/notes

Pro Micro is the only ADC owner.

### TH-011

From device

SparkFun Pro Micro RP2350

From terminal

GP1

To device

CS1238

To terminal

SCK

Signal

Load-cell clock

Expected level/polarity

3.3 V logic

Wire

Short local conductor

Status

planned

Evidence/notes

Do not parallel a second controller.

### TH-012

From device

SparkFun Pro Micro RP2350

From terminal

Qwiic SDA / GPIO16

To device

TMAG5273 Qwiic

To terminal

SDA

Signal

Hall sensor data

Expected level/polarity

3.3 V I2C

Wire

Qwiic cable TBD

Status

bench-verified

Evidence/notes

Corrected E-09 mapping GP16→SDA passed the TMAG5273 identity and far/near/return test.

### TH-013

From device

SparkFun Pro Micro RP2350

From terminal

Qwiic SCL / GPIO17

To device

TMAG5273 Qwiic

To terminal

SCL

Signal

Hall sensor clock

Expected level/polarity

3.3 V I2C

Wire

Qwiic cable TBD

Status

bench-verified

Evidence/notes

Corrected E-09 mapping GP17→SCL passed the TMAG5273 identity and far/near/return test.

### TH-018

From device

LIFT-home microswitch

From terminal

Meter-verified COM/NO pair

To device

SparkFun Pro Micro RP2350

To terminal

GP2 and adjacent local TOOL_GND

Signal

Absolute LIFT_HOME reference at boot/recovery/service, not normal M5

Expected level/polarity

GP2 uses its internal pullup; switch pressed pulls GP2 LOW

Wire

Short local pair

Status

installed; end-to-end input/UART verified; powered T-01G pending

Evidence/notes

Released contact was open/no-beep and pressed contact was continuous/beep before installation. The contact has no electrical polarity: either terminal may connect to GP2, the other to TOOL_GND; leave the NC terminal unused. With the motor-safe UART1 diagnostic flashed and toolhead powered from its known-good 5 V supply, COM8 at 115200 reported lift_home=1 pressed and 0 released. Corrected integrated firmware then reported the Theta toolhead service UART ready line and recurring complete telemetry; manual switch operation yielded the expected lift_home=0 released → 1 pressed → 0 released. Its T-01 actuator direction is not commissioned fault is the intentional motor lock. Mount the switch fixed and its flag on the moving pen carriage. Do not connect 5 V, 6 V, or PC817C CTRL_GND. Powered T-01G must pass before it controls retract. Normal M5 uses load-cell release plus a calibrated clearance pulse and must not routinely actuate this switch.

### TH-014

From device

Toolhead controller

From terminal

FAULT output TBD

To device

RP23CNC

To terminal

Feed hold/halt input TBD

Signal

Tool fault

Expected level/polarity

Fail-safe polarity TBD

Wire

TBD

Status

TBD

Evidence/notes

Later integration phase

### TH-015

From device

Toolhead controller

From terminal

READY output TBD

To device

RP23CNC

To terminal

Auxiliary input TBD

Signal

Contact ready

Expected level/polarity

Optional; polarity TBD

Wire

TBD

Status

TBD

Evidence/notes

Later handshake upgrade

### TH-016

From device

SparkFun Pro Micro RP2350

From terminal

GP20 / UART1 TX

To device

DSD TECH SH-U09C2 USB-to-TTL service adapter

To terminal

RXD

Signal

Toolhead test telemetry

Expected level/polarity

3.3 V UART, 115200 baud; adapter receives Pro Micro output

Wire

Short temporary jumper

Status

bench-verified

Evidence/notes

E-07B UART startup telemetry passed 2026-08-14. Cross TX to adapter RXD; set adapter jumper to 3.3 V. Adapter VCC remains disconnected; this attaches only to TOOL_GND, never PC817C CTRL_GND.

### TH-017

From device

DSD TECH SH-U09C2 USB-to-TTL service adapter

From terminal

TXD

To device

SparkFun Pro Micro RP2350

To terminal

GP21 / UART1 RX

Signal

Toolhead test commands

Expected level/polarity

3.3 V UART, 115200 baud

Wire

Short temporary jumper

Status

bench-verified

Evidence/notes

E-07B UART command path ready; telemetry startup passed 2026-08-14. Cross adapter TXD to Pro Micro RX; adapter GND must connect to TOOL_GND; adapter VCC remains disconnected.

## Communications

### COM-001

From device

Host PC

From terminal

USB TBD

To device

RP23CNC

To terminal

USB-C

Signal

G-code/control

Cable

USB data cable TBD

Status

TBD

Evidence/notes

Baseline transport candidate

### COM-002

From device

Host/network

From terminal

Ethernet

To device

RP23CNC WizNet module

To terminal

Ethernet

Signal

G-code/WebUI/network

Cable

Cat5e or better

Status

TBD

Evidence/notes

Optional adapter/build configuration

### COM-003

From device

microSD card

From terminal

Card contacts

To device

RP23CNC

To terminal

microSD socket

Signal

Offline G-code

Cable

microSD

Status

TBD

Evidence/notes

Optional transport candidate

## Revision log

### 2026-09-10

Date

2026-09-10

Revision

4.7

Change

Moved the existing blue GP27/U3 A_HOME conductor from LIMA SIG to PROBE SIG after direct and real-magnet motor-inert PRB/G38 entry/release checks passed; recorded installed active-low Aux0 command mapping and $6=1.

Updated by

Codex

Related evidence

RPSW-20260910-002; 2026-09-10-e-18-motor-inert-p100-handshake.md

### 2026-09-04

Date

2026-09-04

Revision

4.4

Change

Corrected the visual wiring diagrams to show the axis-specific motor cable colors: X shielded-cable B- is white and continues to the motor's blue lead; Y and A retain stock blue B- leads.

Updated by

Codex

Related evidence

Project-owner clarification; HW-20260904-001

### 2026-09-04

Date

2026-09-04

Revision

4.5

Change

Re-routed the explanatory top-down wiring schematic into separate axis, signal, motor, and power lanes; no connection assignments changed.

Updated by

Codex

Related evidence

HW-20260904-002

### 2026-09-05

Date

2026-09-05

Revision

4.6

Change

Promoted X/Y/A TB6600 signal harnesses from continuity-checked to bench-verified after E-03 installed-driver testing.

Updated by

Codex

Related evidence

HW-20260905-002; 2026-09-05-e-03-tb6600-installed-signal-response.md

### 2026-09-15

Date

2026-09-15

Revision

4.8

Change

Added planned temporary Pico 2 dual-sensor calibration-fixture rows: CS1238 #1 on GP2/GP3 and INA101 output to ADC0. Production Pro Micro GP0/GP1 wiring is unchanged.

Updated by

Codex

Related evidence

HW-20260915-001; PICO2_DUAL_SENSOR_DAQ.md

### 2026-09-16

Date

2026-09-16

Revision

4.9

Change

Added a planned temporary Pro Micro GP1 -> Pico GP14 MOTION_ACTIVE marker and its TOOL_GND signal reference for Pico-clocked actuator-edge timestamps.

Updated by

Codex

Related evidence

HW-20260915-001; PICO2_DUAL_SENSOR_DAQ.md

### 2026-09-16

Date

2026-09-16

Revision

5.0

Change

Corrected the temporary INA101 fixture to show one series-linked dual-output bench supply: if continuity verifies the 5V bridge-excitation terminal, it branches from the +5 V rail rather than a separate supply. Also removed diagram label collisions.

Updated by

Codex

Related evidence

HW-20260915-001; PICO2_DUAL_SENSOR_DAQ.md

### 2026-09-16

Date

2026-09-16

Revision

5.1

Change

Replaced the temporary GP15 momentary START/STOP input with a latching SPST DAQ ON/OFF switch: ON grounds GP15/LOW and OFF releases it/HIGH.

Updated by

Codex

Related evidence

HW-20260915-001; PICO2_DUAL_SENSOR_DAQ.md

### 2026-09-19

Date

2026-09-19

Revision

5.4

Change

Added native Pico 2 fixture firmware for the planned GP2/GP3 CS1238, GP26 ADC0, GP14 marker, GP15 switch, and USB CDC stream. No physical wiring is verified or changed by this source addition.

Updated by

Codex

Related evidence

pico2_dual_sensor_daq; E-09C

### 2026-09-18

Date

2026-09-18

Revision

5.2

Change

Reconciled the instructor INA101KU PCB artwork with TI documentation: the reference load cell is integral to the board; +V/-V are amplifier rails; 5V remains a continuity-gated likely bridge-excitation terminal; 4.3 kOhm is the likely gain resistor and 100 kOhm the likely offset trim.

Updated by

Codex

Related evidence

2026-09-18-ina101ku-instructor-pcb-datasheet-reconciliation.md

### 2026-09-18

Date

2026-09-18

Revision

5.3

Change

Owner confirmed the instructor board's 5V terminal was powered by Arduino 5 V in its original setup. It is now the confirmed reference-bridge excitation input and branches from the fixture's +5 V rail alongside INA +V; no third supply is required.

Updated by

Codex

Related evidence

Owner report; PICO2_DUAL_SENSOR_DAQ.md

### 2026-08-30

Date

2026-08-30

Revision

4.3

Change

Added planned toolhead LIFT-home microswitch input on GP2/TOOL_GND; terminals 1 and 3 are the intended COM/NO pair.

Updated by

Codex

Related evidence

Owner terminal identification; T-01G planned

### 2026-08-22

Date

2026-08-22

Revision

3.5

Change

Documented the implemented dual-core readiness/threshold protocol and controller-resident centroid/A-registration macro. Reused all five routed control conductors; retained LIMA until F-08 authorizes controller-end retermination to PRB.

Updated by

Codex

Related evidence

RPSW-20260822-003; source compile and macro validator only

### 2026-08-22

Date

2026-08-22

Revision

3.4

Change

Corrected stale separate-RP2040-adapter language: the installed SparkFun Pro Micro RP2350 toolhead controller owns both pen-pressure control and TMAG5273 magnetic sensing/output. No wiring changed.

Updated by

Codex

Related evidence

RPSW-20260822-002; current GP27/GP28/GP29 wiring rows

### 2026-08-22

Date

2026-08-22

Revision

3.3

Change

Added motorless F-08 as the gate for the candidate GP27/U3-to-PRB probe path; retained LIMA as the authoritative endpoint until X/A G38 behavior, coordinate reporting, and the actual isolated path pass.

Updated by

Codex

Related evidence

RPSW-20260822-001; F-08 planned

### 2026-08-21

Date

2026-08-21

Revision

3.2

Change

Recorded physical segregation of the mains-input and DC-output conductor routes at the main-supply/fuse-block area.

Updated by

Codex

Related evidence

Owner report; HW-20260821-001

### 2026-08-20

Date

2026-08-20

Revision

3.1

Change

Recorded a partial E-11 no-load power-path check: the HD064RT input and one output pair measured 12.05 VDC, with polarity matching the block markings.

Updated by

Codex

Related evidence

2026-08-20-e-11-main-supply-no-load-path-test.md

### 2026-08-19

Date

2026-08-19

Revision

3.0

Change

Recorded the actual HD064RT output allocation: RP23CNC on OUT1, Pololu D36V50F6 on OUT4, and X/Y/A TB6600s on OUT6/OUT7/OUT8; OUT2/OUT3/OUT5 are unused. Recorded selected branch-fuse starting values pending physical confirmation.

Updated by

Codex

Related evidence

Project-owner allocation report; HW-20260819-004

### 2026-08-23

Date

2026-08-23

Revision

3.6

Change

Superseded the prior shield assignment: only X now has the grounded motor-cable sheath; Y and A are unshielded, with black/green and red/blue coil pairs.

Updated by

Codex

Related evidence

Project-owner note; HW-20260823-002

### 2026-08-23

Date

2026-08-23

Revision

3.7

Change

Corrected the X shielded-run Phase B colors: B+ is red and B- is white, with white continuing the motor's blue B- lead.

Updated by

Codex

Related evidence

Project-owner correction; HW-20260823-003

### 2026-08-23

Date

2026-08-23

Revision

3.8

Change

Recorded the owner-reported mains color convention: red L, blue N, and green PE; the green X sheath/drain is landed at PE.

Updated by

Codex

Related evidence

Project-owner report; HW-20260823-004

### 2026-08-23

Date

2026-08-23

Revision

3.9

Change

Verified the red/blue/green mains terminal identities and the green X sheath landing at the protective-earth terminal. PE/chassis continuity and powered tests remain open.

Updated by

Codex

Related evidence

Project-owner verification; HW-20260823-005

### 2026-08-23

Date

2026-08-23

Revision

4.0

Change

Verified the X sheath has no continuity to DC -V; PE/chassis and motor-phase isolation remain open.

Updated by

Codex

Related evidence

Project-owner measurement; HW-20260823-006

### 2026-08-23

Date

2026-08-23

Revision

4.1

Change

Verified the power-supply PE terminal-to-chassis path; the powder-coated machine structure is not the PE reference.

Updated by

Codex

Related evidence

Project-owner measurement; HW-20260823-007

### 2026-08-23

Date

2026-08-23

Revision

4.2

Change

Verified the X sheath has no continuity to any motor-phase conductor; its PE bond and DC -V isolation are complete.

Updated by

Codex

Related evidence

Project-owner measurement; HW-20260823-008

### 2026-08-19

Date

2026-08-19

Revision

2.9

Change

Corrected motor-cable installation: only Y has a shield/drain; X and A retain their supplied unshielded 24 AWG leads. Removed the nonexistent X/A shield-bond rows.

Updated by

Codex

Related evidence

Superseded by HW-20260823-002.

### 2026-08-19

Date

2026-08-19

Revision

2.8

Change

Recorded E-01 hand-turn coil-pair results for all three 17HS15 motors: black/green and red/blue. The Y axis has the special shielded-cable splice: cable black/green continues motor black/green, while cable red/white continues motor red/blue.

Updated by

Codex

Related evidence

Owner hand-turn generated-voltage test; 2026-08-19-e-01-y-stepper-coil-pair-test.md

### 2026-09-13

Date

2026-09-13

Revision

4.8

Change

Corrected the confirmed installed DRV8833 module-label mapping without solder rework: GP6 drives EEP/sleep and GP7 reads ULT/fault. The prior opposite-role record is superseded; reflash and re-run E-14C/T-01 before relying on driver behavior.

Updated by

Codex

Related evidence

Owner-confirmed installed-board photo; HW-20260913-001; E-14C function re-test required

### 2026-08-13

Date

2026-08-13

Revision

2.7

Change

Historical record superseded 2026-09-13: it incorrectly assigned the installed module's ULT/EEP roles.

Updated by

Codex

Related evidence

See revision 2.8 and HW-20260913-001.

### 2026-08-12

Date

2026-08-12

Revision

1.4

Change

Recorded manufacturer-confirmed uxcell load-cell mapping: Red EXC+ to HX711 E+, Black EXC- to E-, Green SEN+ to A+, White SEN- to A-

Updated by

Codex

Related evidence

Owner-supplied product specification; E-07 still required

### 2026-08-10

Date

2026-08-10

Revision

2.5

Change

Reassigned PC817 tool-side pins to direct-header GP29/GP28/GP27 and recorded separate 1×4 DRV8833 plus 1×6 PC817 JST harnesses; reset is intentionally NC

Updated by

Codex

Related evidence

PRO_MICRO_JST_HARNESS.md; E-18 harness re-test required

### 2026-08-10

Date

2026-08-10

Revision

2.4

Change

Completed simulated-input tests for U1/U2/U3 and confirmed controller/tool ground isolation; removed the rebuild-only R6 gate for the tested U3 sample

Updated by

Codex

Related evidence

2026-08-10-e-18-pc817-interface-bench-test.md; F-05 remains required

### 2026-08-10

Date

2026-08-10

Revision

2.3

Change

Replaced the invalid recovered route with the 38-segment minimum-wire v2 design, changed unavailable GP10 to exposed GPIO20, and recorded the U1/U3 bench evidence

Updated by

Codex

Related evidence

pc817-perfboard-v2-minwire.kicad_pcb; E-18 lab note; DRC/ERC reports

### 2026-08-06

Date

2026-08-06

Revision

2.1

Change

Replaced the two five-pin headers with one six-pin 2.54 mm screw terminal on each short side; pin 6 is intentionally NC/spare on both blocks

Updated by

Codex

Related evidence

pc817-perfboard-v1.2.kicad_pcb; F-05/E-18 remain required

### 2026-08-09

Date

2026-08-09

Revision

2.2

Change

Verified RP23CNC V1.0 LIMA as a 12 V active-low sink input; blocked the generic-PC817C U3/A_HOME connection because its 50% guaranteed CTR cannot guarantee the approximately 5.3 mA controller input current

Updated by

Codex

Related evidence

RP23CNC Schematic/V1.0 schematic.pdf, page 4; BOJACK PC817C listing / BOM

### 2026-08-06

Date

2026-08-06

Revision

2.0

Change

Superseded the unrouted SMD PCB placement with an all-through-hole 14 × 6 perfboard component/underside-wire map and matching KiCad THT assembly view

Updated by

Codex

Related evidence

PERFBOARD_BUILD.md; pc817-perfboard-v1.1.kicad_pcb; F-05/E-18 remain required

### 2026-08-06

Date

2026-08-06

Revision

1.9

Change

Corrected the PC817 U1/U2 firmware contract to active-low GP8/GP10, changed the inputs to use the module's external 10 kΩ pullups, and added a separately named unrouted two-layer PCB review placement

Updated by

Codex

Related evidence

pc817-interface-v0.2.kicad_pcb; F-05/E-18 remain required

### 2026-08-06

Date

2026-08-06

Revision

1.8

Change

Replaced the proposed JST-GH PCB concept with a KiCad PC817C perfboard schematic using axial parts and 2.54 mm right-angle headers; rejected the B07WFGTNQC as an unverified RP2350 3.3 V interface

Updated by

Codex

Related evidence

hardware/pc817-interface/pc817-interface.sch; E-18 remains required

### 2026-08-06

Date

2026-08-06

Revision

1.7

Change

Added proposed 40.16 × 22.65 mm three-channel PC817C module layout with 90° JST GH connectors; retained B07WFGTNQC as the selected interface and R6/A_HOME verification gate

Updated by

Codex

Related evidence

pc817-three-channel-module-proposal.png; E-18 remains required

### 2026-08-03

Date

2026-08-03

Revision

1.6

Change

Added B07WFGTNQC optocoupler module wiring for RP23CNC-to-Pro-Micro M3/M5 and HOME_ARM command inputs while leaving reverse A_HOME path as a separate verification item

Updated by

Codex

Related evidence

power-distribution-schematic.png; Amazon B07WFGTNQC listing

### 2026-08-03

Date

2026-08-03

Revision

1.5

Change

Added dedicated power-distribution document and PNG/SVG schematic showing the active D36V50F6 6 V rail, toolhead S7V8F5 5 V regulator, 12 V branch loads, and remaining fuse/terminal/wire-gauge TBDs

Updated by

Codex

Related evidence

docs/hardware/POWER_DISTRIBUTION.md; power-distribution-schematic.png

### 2026-08-03

Date

2026-08-03

Revision

1.4

Change

Added explanatory RP23CNC-to-Pro-Micro interface schematic PNG/SVG for the HiLetgo logic-level shifter and Zopsc A_HOME optocoupler paths while keeping exact RP23CNC terminals and common points unverified

Updated by

Codex

Related evidence

rp23cnc-pro-micro-interface-schematic.png

### 2026-08-02

Date

2026-08-02

Revision

1.3

Change

Added purchased KWANGIL 20 AWG 4C AMESB shielded stepper cable, conductor assignment guidance, and one-end shield/drain bonding rows for X/Y/A motor cables

Updated by

Codex

Related evidence

Project-owner purchase note; Amazon listing for KWANGIL B0GVBF51Q7

### 2026-08-02

Date

2026-08-02

Revision

1.2

Change

Added purchased Pololu S7V8F5 local 5 V toolhead regulator, selected Pololu D36V50F6 as the DIN-side fixed 6 V toolhead regulator, and clarified that the toolhead Pro Micro reads TMAG5273 and outputs GP9 A_HOME gated by RP23CNC Aux 0 -> GP10 HOME_ARM through a 5 V-to-3.3 V interface

Updated by

Codex

Related evidence

Project-owner purchase note; Pololu S7V8F5 and D36V50F6 product pages; toolhead-wiring-diagram.svg

### 2026-07-31

Date

2026-07-31

Revision

1.1

Change

Added SparkFun Pro Micro RP2350 toolhead prototype pin choices for DRV8833, HX711, TMAG5273, and M3/M5 input while retaining bench-test status

Updated by

Codex

Related evidence

toolhead-wiring-diagram.svg

### 2026-07-04

Date

2026-07-04

Revision

1.0

Change

Added an explanatory electronics layout and wiring concept HTML while retaining this table as the authority for terminal labels, connection status, and evidence

Updated by

Codex

Related evidence

docs/electronics_layout_and_wiring.html

### 2026-07-04

Date

2026-07-04

Revision

0.9

Change

Added planned TMAG5273/RP2040 magnetic bed calibration adapter, center magnet, outer theta-index magnet, and gated A_HOME interface placeholders

Updated by

Codex

Related evidence

firmware/grblhal/HOMING_AND_MAGNETIC_CALIBRATION.md

### 2026-06-09

Date

2026-06-09

Revision

0.8

Change

Confirmed received controller as RP23U5XBB V1.01 from front silkscreen; recorded visible connector and Wiz850io socket installation while retaining E-17 inspection and continuity gates

Updated by

Codex

Related evidence

docs/report/lab-notes/2026-06-09-rp23u5xbb-v1.01-board-inspection.md

### 2026-06-06

Date

2026-06-06

Revision

0.7

Change

Identified purchased RP23CNC variant as With Assembly and Ethernet Kits; added required soldering and inspection gate before pin assignment or power

Updated by

Codex

Related evidence

Brookwood Design variant 48493912129751

### 2026-06-06

Date

2026-06-06

Revision

0.6

Change

Replaced the fixed 5 V actuator candidate with purchased B085T73CSD adjustable modules; target output is 6.0 V and the claimed 5 A maximum remains subject to load/thermal testing

Updated by

Codex

Related evidence

Amazon listing and tests E-14/E-15

### 2026-06-06

Date

2026-06-06

Revision

0.5

Change

Added B0F1WB3LJ5 fixed 5 V buck as a toolhead bench-test candidate; final acceptance depends on measured actuator current, ripple, and temperature

Updated by

Codex

Related evidence

Amazon listing and tests E-06/E-14

### 2026-06-06

Date

2026-06-06

Revision

0.4

Change

Corrected received model to S-120-12; documented terminals 1-7 and +V ADJ from the physical unit; split AC line, neutral, and protective-earth conductors; archived QR-linked PDF

Updated by

Codex

Related evidence

Owner inspection and references/MEISHILE-S-120-12-manual.pdf

### 2026-06-06

Date

2026-06-06

Revision

0.3

Change

Added internally consistent same-ASIN reseller details: reported model SE-1500-12, 50/60 Hz, approximate size/weight, protection claims, and no included connectors. Rejected contradictory 30 A/360 W text as unrelated listing contamination.

Updated by

Codex

Related evidence

Ubuy product page supplied by project owner

### 2026-06-06

Date

2026-06-06

Revision

0.2

Change

Added selected MEISHILE B0781ZJ7GP 12 V, 10 A, 120 W supply and updated proposed 12 V distribution

Updated by

Codex

Related evidence

Amazon listing supplied by project owner

### 2026-06-06

Date

2026-06-06

Revision

0.1

Change

Created master table from current BOM, interface contract, and conceptual diagram; all unverified terminals retained as TBD

Updated by

Codex

Related evidence

Repository organization phase

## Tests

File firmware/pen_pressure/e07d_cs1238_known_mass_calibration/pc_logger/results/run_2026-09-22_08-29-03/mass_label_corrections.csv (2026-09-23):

applied_local | operation | fixture_mass_g | point_count
2026-09-22T09:04:48 | added constant fixture mass to all physical mass labels | 2.5 | 19

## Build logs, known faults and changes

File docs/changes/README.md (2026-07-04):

# Change Documentation

This directory is the searchable record of what changed by subsystem. It
complements, rather than replaces, the single chronological
[`ENGINEERING_LOG.md`](../project/ENGINEERING_LOG.md).

## Find a change

| Area | Scope | Index |
|---|---|---|
| Windows software | Qt converter, conversion engine, launcher, desktop workflow | [`windows-software/README.md`](windows-software/README.md) |
| RP23CNC software | grblHAL, controller settings/plugins, machine-side firmware | [`rp23cnc-software/README.md`](rp23cnc-software/README.md) |
| Hardware | Mechanics, electronics, wiring, power, enclosure, physical tests | [`hardware/README.md`](hardware/README.md) |

The combined reverse-chronological index is [`INDEX.md`](INDEX.md).

## Record format

Each meaningful change gets one canonical Markdown note using
[`_templates/CHANGE_NOTE.md`](_templates/CHANGE_NOTE.md). Notes contain
searchable metadata, the reason for the change, implementation details,
verification, failures, risks, and links to affected files.

Use these stable category IDs:

- `WSW`: Windows software
- `RPSW`: RP23CNC and machine-side software
- `HW`: hardware, wiring, and mechanics

IDs use `<category>-YYYYMMDD-NNN`, for example `WSW-20260607-001`.

## Rules

1. Put the canonical note in the dominant subsystem directory.
2. List every affected category in the note metadata.
3. Run `python tools\docs_index.py --write`; indexes are generated from note
   metadata.
4. Keep one subject per note. Split unrelated work.
5. Update an existing note for follow-up evidence about the same change.
6. Create a new note when behavior, design intent, wiring, or configuration
   changes again.
7. Link detailed bench results to a lab note rather than copying raw data.

Lab notes are indexed in
[`../report/lab-notes/README.md`](../report/lab-notes/README.md).

Useful searches:

```powershell
rg -n "preview|grblHAL|wiring" docs\changes
rg -n "status: (planned|implemented|failed)" docs\changes
rg -n "tags:.*safety|tags:.*breaking-change" docs\changes
```

Validate metadata, generated indexes, duplicate IDs, and local links with:

```powershell
python tools\docs_index.py --check
```

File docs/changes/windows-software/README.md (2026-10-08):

# Windows Software Changes

Scope: the PySide6 Windows converter, conversion engine, launcher, desktop
workflow, and converter-specific samples.

Newest changes appear first.

<!-- BEGIN GENERATED CHANGES -->
| Date | ID | Status | Summary | Tags |
|---|---|---|---|---|
| 2026-10-08 | `WSW-20261008-018` | implemented | [Brightness reaches 20 % and GCR tops out at 100 %](2026-10-08-cmyk-brightness-and-gcr-limits.md) | `cmyk`, `controls`, `gcr`, `brightness` |
| 2026-10-08 | `WSW-20261008-017` | implemented | [Rectilinear pitch follows the inked tone and eases between rows](2026-10-08-cmyk-rectilinear-pitch-easing.md) | `cmyk`, `screening`, `rectilinear`, `banding` |
| 2026-10-08 | `WSW-20261008-016` | implemented | [Auto renders the screen before it picks the tone](2026-10-08-cmyk-auto-models-the-screen.md) | `cmyk`, `automation`, `screening`, `density` |
| 2026-10-08 | `WSW-20261008-015` | implemented | [The ink simulation stops multiplying ink it cannot draw](2026-10-08-cmyk-preview-subpixel-ink.md) | `cmyk`, `preview`, `ink-simulation`, `fidelity` |
| 2026-10-08 | `WSW-20261008-014` | implemented | [Auto matches the printed tone to the photo](2026-10-08-cmyk-auto-matches-tone.md) | `cmyk`, `automation`, `tone`, `portraits` |
| 2026-10-08 | `WSW-20261008-013` | implemented | [Ink profile button no longer kills the app](2026-10-08-cmyk-ink-profile-button-crash.md) | `cmyk`, `preview`, `crash`, `ink-profile` |
| 2026-10-08 | `WSW-20261008-012` | implemented | [Auto (photo) also matches the pen pitch](2026-10-08-cmyk-auto-matches-pen.md) | `cmyk`, `screening`, `automation`, `pitch` |
| 2026-10-08 | `WSW-20261008-011` | implemented | [Auto reads the colourful quartile for saturation and GCR](2026-10-08-cmyk-auto-chroma-quartile.md) | `cmyk`, `automation`, `color-separation` |
| 2026-10-08 | `WSW-20261008-010` | implemented | [Auto (photo) now searches for detail legibility](2026-10-08-cmyk-auto-detail-search.md) | `cmyk`, `automation`, `tone`, `defaults` |
| 2026-10-08 | `WSW-20261008-009` | implemented | [Add registration crosses and a pen-width pitch helper](2026-10-08-cmyk-registration-and-pitch-helper.md) | `cmyk`, `registration`, `workflow`, `user-interface` |
| 2026-10-08 | `WSW-20261008-008` | implemented | [Load measured ink profiles into the simulation](2026-10-08-cmyk-ink-profile-loading.md) | `cmyk`, `calibration`, `ink-simulation` |
| 2026-10-08 | `WSW-20261008-007` | implemented | [Blend the CMYK layer SVGs multiplicatively](2026-10-08-cmyk-svg-multiply-blend.md) | `cmyk`, `svg`, `preview` |
| 2026-10-08 | `WSW-20261008-006` | implemented | [Add an Auto (photo) button to the CMYK image options](2026-10-08-cmyk-auto-photo-button.md) | `cmyk`, `user-interface`, `defaults`, `automation` |
| 2026-10-08 | `WSW-20261008-005` | implemented | [Set the CMYK defaults to the owner's gamma-led tuning](2026-10-08-cmyk-gamma-led-defaults.md) | `cmyk`, `defaults`, `gamma`, `tone` |
| 2026-10-08 | `WSW-20261008-004` | implemented | [Extend contrast past 200 % and push colour into the mix](2026-10-08-cmyk-contrast-headroom-color.md) | `cmyk`, `contrast`, `tone`, `defaults` |
| 2026-10-08 | `WSW-20261008-003` | implemented | [Add a brightness lift and restore contrast to 200 %](2026-10-08-cmyk-brightness-control.md) | `cmyk`, `tone`, `brightness`, `defaults` |
| 2026-10-08 | `WSW-20261008-002` | implemented | [Open rectilinear light tones instead of hatching them](2026-10-08-cmyk-rectilinear-light-stretch.md) | `cmyk`, `rectilinear`, `tone`, `screening` |
| 2026-10-08 | `WSW-20261008-001` | implemented | [Soften the CMYK tone curve and rebalance the defaults](2026-10-08-cmyk-soft-contrast-defaults.md) | `cmyk`, `tone`, `contrast`, `defaults`, `rectilinear` |
| 2026-10-07 | `WSW-20261007-025` | implemented | [Set the CMYK defaults to the owner's tuned rectilinear set](2026-10-07-cmyk-owner-tuned-rectilinear-defaults.md) | `cmyk`, `defaults`, `rectilinear` |
| 2026-10-07 | `WSW-20261007-024` | implemented | [Tune the CMYK defaults for the rectilinear fill](2026-10-07-cmyk-rectilinear-defaults.md) | `cmyk`, `defaults`, `rectilinear` |
| 2026-10-07 | `WSW-20261007-023` | implemented | [Ink simulation draws at the real pen width and explains the pitch chain](2026-10-07-cmyk-ink-sim-pen-width.md) | `cmyk`, `preview`, `ink-simulation` |
| 2026-10-07 | `WSW-20261007-022` | implemented | [Add an ink-simulation (multiply) preview for CMYK](2026-10-07-cmyk-ink-simulation-preview.md) | `cmyk`, `preview`, `opengl`, `ink-simulation` |
| 2026-10-07 | `WSW-20261007-021` | implemented | [Fix rectilinear stitching on multi-dash rows](2026-10-07-cmyk-rectilinear-stitch-fix.md) | `cmyk`, `rectilinear`, `bugfix` |
| 2026-10-07 | `WSW-20261007-020` | implemented | [Add a rectilinear fill screen that joins rows](2026-10-07-cmyk-rectilinear-fill.md) | `cmyk`, `screening`, `rectilinear`, `pen-cycles` |
| 2026-10-07 | `WSW-20261007-019` | implemented | [Show per-ink M3 counts in the preview data area](2026-10-07-cmyk-preview-m3-counts.md) | `cmyk`, `preview`, `user-interface` |
| 2026-10-07 | `WSW-20261007-018` | implemented | [Filter CMYK preview layers live instead of re-rendering](2026-10-07-cmyk-live-preview-layers.md) | `cmyk`, `preview`, `opengl`, `user-interface` |
| 2026-10-07 | `WSW-20261007-017` | implemented | [Apply the CMYK Artwork scale to the screened marks](2026-10-07-cmyk-artwork-scale.md) | `cmyk`, `bugfix`, `user-interface` |
| 2026-10-07 | `WSW-20261007-016` | implemented | [Raise the CMYK max-marks cap](2026-10-07-cmyk-max-marks-cap.md) | `cmyk`, `user-interface`, `screening` |
| 2026-10-07 | `WSW-20261007-015` | implemented | [Set the CMYK defaults to the owner's tuned workflow](2026-10-07-cmyk-owner-defaults.md) | `cmyk`, `defaults`, `crosshatch`, `user-interface` |
| 2026-10-07 | `WSW-20261007-014` | implemented | [Extend crosshatch screens past four families](2026-10-07-cmyk-crosshatch-levels.md) | `cmyk`, `screening`, `crosshatch` |
| 2026-10-07 | `WSW-20261007-013` | implemented | [Raise the CMYK resolution cap for large sources](2026-10-07-cmyk-resolution-cap.md) | `cmyk`, `resolution`, `user-interface` |
| 2026-10-07 | `WSW-20261007-012` | implemented | [Print the calibration mix cells at the dense spot spacing](2026-10-07-cmyk-dense-mix-cells.md) | `cmyk`, `calibration`, `test-print`, `ai-handoff` |
| 2026-10-07 | `WSW-20261007-011` | implemented | [Add the C+M+Y+K quad to the calibration mixes](2026-10-07-cmyk-calibration-quad-mix.md) | `cmyk`, `calibration`, `test-print`, `ai-handoff` |
| 2026-10-07 | `WSW-20261007-010` | implemented | [Strip the calibration sheet to what a scan needs](2026-10-07-cmyk-quiet-calibration-sheet.md) | `cmyk`, `calibration`, `test-print`, `ai-handoff`, `line-screen` |
| 2026-10-07 | `WSW-20261007-009` | implemented | [Make CMYK calibration scans analyzable from the image alone](2026-10-07-cmyk-calibration-ai-handoff.md) | `cmyk`, `calibration`, `test-print`, `ai-handoff`, `tools` |
| 2026-10-07 | `WSW-20261007-008` | implemented | [Let the CMYK calibration sheet follow the screen style](2026-10-07-cmyk-calibration-line-screens.md) | `cmyk`, `calibration`, `line-screen`, `crosshatch`, `test-print` |
| 2026-10-07 | `WSW-20261007-007` | implemented | [Add a labeled CMYK calibration sheet and scan tool](2026-10-07-cmyk-calibration-sheet.md) | `cmyk`, `calibration`, `test-print`, `color-separation`, `tools` |
| 2026-10-07 | `WSW-20261007-006` | implemented | [Add a Red motion lines toggle to the preview panel](2026-10-07-preview-motion-lines-toggle.md) | `preview`, `user-interface`, `opengl` |
| 2026-10-07 | `WSW-20261007-005` | implemented | [Photo-ready CMYK defaults: auto levels, solid dots, 1.2 mm pitch](2026-10-07-cmyk-photo-defaults.md) | `cmyk`, `defaults`, `auto-levels`, `halftone`, `photo` |
| 2026-10-07 | `WSW-20261007-004` | implemented | [Plan the four CMYK programs automatically; drop the Analyze button](2026-10-07-cmyk-background-planning.md) | `cmyk`, `workflow`, `preview`, `cost-analysis`, `x-theta`, `y-theta` |
| 2026-10-07 | `WSW-20261007-003` | implemented | [Draw the CMYK preview per ink colour](2026-10-07-cmyk-ink-preview.md) | `cmyk`, `opengl`, `preview`, `color-separation`, `generator-tabs` |
| 2026-10-07 | `WSW-20261007-002` | implemented | [Add six CMYK mark styles and an overdraw control](2026-10-07-cmyk-mark-styles.md) | `cmyk`, `color-separation`, `screening`, `line-screen`, `tsp`, `contours`, `gcode` |
| 2026-10-07 | `WSW-20261007-001` | implemented | [Add the CMYK separation tool with one G-code file per ink](2026-10-07-cmyk-separation-tool.md) | `cmyk`, `color-separation`, `generator-tabs`, `gcode`, `cost-analysis`, `x-theta`, `y-theta` |
| 2026-10-06 | `WSW-20261006-031` | implemented | [Raise the pen-up dwell default to 1000 ms](2026-10-06-pen-up-dwell-1000ms.md) | `converter`, `pen`, `timing` |
| 2026-10-06 | `WSW-20261006-030` | implemented | [Fix Vector Trace closed loops collapsing to invisible paths](2026-10-06-vector-trace-closed-loop-fix.md) | `generators`, `bug-fix`, `vector-trace` |
| 2026-10-06 | `WSW-20261006-029` | implemented | [High-quality tier: Stipple/TSP, Reaction-Diffusion, and Vector Trace](2026-10-06-high-quality-stipple-rd-trace.md) | `generators`, `quality` |
| 2026-10-06 | `WSW-20261006-028` | implemented | [Add Plotterfun, Voronoi, Path Prep, and Layers tools](2026-10-06-plotterfun-voronoi-path-prep-layers.md) | `user-interface`, `generators` |
| 2026-10-06 | `WSW-20261006-027` | implemented | [Group tools by input type: Photo-based and Algorithm only](2026-10-06-photo-vs-algorithm-groups.md) | `user-interface`, `navigation`, `generators` |
| 2026-10-06 | `WSW-20261006-026` | implemented | [Recommended default settings for every tool](2026-10-06-recommended-default-settings.md) | `user-interface`, `generators`, `defaults` |
| 2026-10-06 | `WSW-20261006-025` | implemented | [Tool accuracy audit and source-parity fixes](2026-10-06-tools-accuracy-audit-fixes.md) | `generators`, `fidelity`, `audit` |
| 2026-10-06 | `WSW-20261006-024` | implemented | [Add SquiggleCam, Pixel Art, and Wobble tools](2026-10-06-squigglecam-pixel-art-wobble.md) | `user-interface`, `generators` |
| 2026-10-06 | `WSW-20261006-023` | implemented | [Flow Field formula source](2026-10-06-flow-field-formulas.md) | `generators`, `flow-field`, `fidelity` |
| 2026-10-06 | `WSW-20261006-022` | implemented | [Add File / Tools / View / Help menus and move tool selection into Tools](2026-10-06-menu-bar-navigation.md) | `user-interface`, `navigation` |
| 2026-10-06 | `WSW-20261006-021` | implemented | [Replace the tab bar with an All tools dashboard](2026-10-06-all-tools-dashboard.md) | `user-interface`, `navigation` |
| 2026-10-06 | `WSW-20261006-020` | implemented | [Generator fidelity audit, restored options, and attribution corrections](2026-10-06-fidelity-audit-and-restorations.md) | `generators`, `documentation`, `fidelity` |
| 2026-10-06 | `WSW-20261006-019` | implemented | [Raise Artwork scale to 1000 percent](2026-10-06-artwork-scale-range-1000.md) | `user-interface`, `generators`, `scale` |
| 2026-10-06 | `WSW-20261006-018` | implemented | [Add Text, Substitution, and Postcard generator tabs](2026-10-06-text-substitution-postcard-tabs.md) | `user-interface`, `generators`, `text` |
| 2026-10-06 | `WSW-20261006-017` | implemented | [Plot generator pages 1:1 so Artwork scale works](2026-10-06-generator-1to1-preview.md) | `user-interface`, `generators`, `scale` |
| 2026-10-06 | `WSW-20261006-016` | implemented | [Add Harmonograph, Snowflake, and Truchet tabs](2026-10-06-harmonograph-snowflake-truchet-tabs.md) | `user-interface`, `generators` |
| 2026-10-06 | `WSW-20261006-015` | implemented | [Artwork scale control on every generator tab](2026-10-06-artwork-scale-on-every-tab.md) | `user-interface`, `generators`, `scale` |
| 2026-10-06 | `WSW-20261006-014` | implemented | [Generator controls fill the settings column](2026-10-06-generator-controls-fill-column.md) | `user-interface`, `generators`, `layout` |
| 2026-10-06 | `WSW-20261006-013` | implemented | [Settings pane fills its column and removes the dead strip](2026-10-06-settings-pane-fills-column.md) | `user-interface`, `layout`, `preview` |
| 2026-10-06 | `WSW-20261006-012` | implemented | [Lift the tab bar above the import and save row](2026-10-06-tab-bar-above-import-row.md) | `user-interface`, `layout` |
| 2026-10-06 | `WSW-20261006-011` | implemented | [Make the settings pane content-width so the preview fills the rest](2026-10-06-content-width-settings-pane.md) | `user-interface`, `preview`, `layout` |
| 2026-10-06 | `WSW-20261006-010` | implemented | [Remove the G-code command list and let the preview fill the workspace](2026-10-06-remove-gcode-command-list.md) | `user-interface`, `preview` |
| 2026-10-06 | `WSW-20261006-009` | implemented | [Put the G-code output to the right of the preview](2026-10-06-gcode-output-right-of-preview.md) | `user-interface`, `preview`, `gcode` |
| 2026-10-06 | `WSW-20261006-008` | implemented | [Move Preview and Cancel into the preview panel](2026-10-06-preview-buttons-in-preview-panel.md) | `user-interface`, `preview` |
| 2026-10-06 | `WSW-20261006-007` | implemented | [Tab-driven preview in the shared preview panel](2026-10-06-tab-driven-shared-preview.md) | `user-interface`, `generators`, `preview` |
| 2026-10-06 | `WSW-20261006-006` | implemented | [Remove redundant per-tab image pickers](2026-10-06-remove-redundant-tab-imports.md) | `user-interface`, `generators`, `import` |
| 2026-10-06 | `WSW-20261006-005` | implemented | [Keep import, export, and preview static across generator tabs](2026-10-06-static-import-export-preview.md) | `user-interface`, `generators`, `preview` |
| 2026-10-06 | `WSW-20261006-004` | implemented | [3D Wireframe generator tab](2026-10-06-3d-wireframe-tab.md) | `user-interface`, `generators`, `3d` |
| 2026-10-06 | `WSW-20261006-003` | implemented | [Line Draw generator tab](2026-10-06-line-draw-tab.md) | `user-interface`, `generators`, `line-art` |
| 2026-10-06 | `WSW-20261006-002` | implemented | [Flow Field generator tab](2026-10-06-flow-field-tab.md) | `user-interface`, `generators`, `flow-field` |
| 2026-10-06 | `WSW-20261006-001` | implemented | [Generator tab shell in the main converter window](2026-10-06-generator-tab-shell.md) | `user-interface`, `generators`, `converter` |
| 2026-10-04 | `WSW-20261004-004` | implemented | [Terrain: stop stacking contours on hard outlines](2026/2026-10-04-terrain-outline-thinning.md) | `fill`, `shading`, `terrain`, `topographic`, `image-tone`, `plotter-art` |
| 2026-10-04 | `WSW-20261004-003` | implemented | [Terrain on image tone follows the photo's shading](2026/2026-10-04-terrain-follows-image-tone.md) | `fill`, `shading`, `terrain`, `topographic`, `image-tone`, `plotter-art` |
| 2026-10-04 | `WSW-20261004-002` | implemented | [Terrain fill: topographic contour shading](2026/2026-10-04-terrain-fill-pattern.md) | `fill`, `shading`, `terrain`, `topographic`, `image-tone`, `plotter-art` |
| 2026-10-04 | `WSW-20261004-001` | implemented | [Default the GP27 handshake and recover options on](2026/2026-10-04-default-gp27-handshake-and-recover.md) | `converter`, `gp27`, `p115`, `handshake`, `pen-dwell`, `defaults` |
| 2026-10-03 | `WSW-20261003-001` | implemented | [Stipple, halftone and single-line (TSP) photo shading](2026/2026-10-03-stipple-halftone-single-line-shading.md) | `fill`, `shading`, `stipple`, `halftone`, `tsp`, `image-tone`, `plotter-art` |
| 2026-10-02 | `WSW-20261002-001` | implemented | [Add an independent Maps tab to the kaleidoscope app](2026/2026-10-02-add-plotting-maps-tab.md) | `kaleidoscope`, `maps`, `openstreetmap`, `tab`, `webengine`, `vendored` |
| 2026-10-01 | `WSW-20261001-010` | implemented | [Theta: no bed sweep the machine cannot follow](2026/2026-10-01-theta-centre-sweep-and-travel-limits.md) | `theta`, `kinematics`, `drift`, `safety`, `calibration` |
| 2026-10-01 | `WSW-20261001-009` | implemented | [Auto fit measures the artwork before it fills it](2026/2026-10-01-auto-fit-measures-before-filling.md) | `fill`, `performance`, `fit`, `interface` |
| 2026-10-01 | `WSW-20261001-008` | implemented | [Photos import directly and plot as sine-wave tone](2026/2026-10-01-photo-raster-input.md) | `fill`, `tone`, `raster`, `photo`, `interface` |
| 2026-10-01 | `WSW-20261001-007` | implemented | [Image-tone fill spacing is millimetres on paper](2026/2026-10-01-image-tone-fill-spacing-units.md) | `fill`, `tone`, `performance`, `units` |
| 2026-10-01 | `WSW-20261001-006` | implemented | [Ornament spacing: the wallpaper density is a control, not a constant](2026/2026-10-01-ornament-spacing-control.md) | `kaleidoscope`, `generative`, `interface` |
| 2026-10-01 | `WSW-20261001-005` | implemented | [The kaleidoscope control column scrolls instead of running off the window](2026/2026-10-01-scrollable-kaleidoscope-sidebar.md) | `kaleidoscope`, `interface`, `usability` |
| 2026-10-01 | `WSW-20261001-004` | implemented | [Sine gradient: gradient tone plotted as continuous adjacent sinusoids](2026/2026-10-01-sine-gradient-fill.md) | `fill`, `gradient`, `tone`, `plotter-art` |
| 2026-10-01 | `WSW-20261001-003` | implemented | [Sparse ornaments: the bead, stud and dot rows stop carpeting the design](2026/2026-10-01-sparse-ornament-layers.md) | `kaleidoscope`, `generative`, `style` |
| 2026-10-01 | `WSW-20261001-002` | implemented | [Region overlay: neighbouring bands braid instead of tiling](2026/2026-10-01-region-overlay.md) | `kaleidoscope`, `generative`, `interface` |
| 2026-10-01 | `WSW-20261001-001` | implemented | [The centre wobble was the Tolerance budget, and it is now reported](2026/2026-10-01-tolerance-drives-inner-imprecision.md) | `kaleidoscope`, `tolerance`, `kinematics`, `diagnosis` |
| 2026-10-01 | `RPSW-20261001-001` | verified | [Lower the A-axis maximum rate to 20000 motor deg/min](../rp23cnc-software/2026/2026-10-01-a-axis-rate-limit-20000.md) | `grblhal`, `settings`, `theta`, `drift`, `safety` |
| 2026-09-30 | `WSW-20260930-023` | implemented | [Keep the commanded A small: re-register the bed each contour](2026/2026-09-30-theta-reregistration.md) | `theta`, `kinematics`, `drift`, `calibration` |
| 2026-09-30 | `WSW-20260930-022` | implemented | [Pen tip diameter for the installed Pigma Micron 005](2026/2026-09-30-pen-width-control.md) | `pen`, `interface`, `gcode` |
| 2026-09-30 | `WSW-20260930-021` | implemented | [Theta drift: record the ratio in the G-code and ship a calibration plot](2026/2026-09-30-theta-drift-diagnosis-and-calibration-plot.md) | `theta`, `kinematics`, `calibration`, `diagnostics` |
| 2026-09-30 | `WSW-20260930-020` | implemented | [Kaleidoscope: close the empty bands in motif patterns](2026/2026-09-30-kaleidoscope-fill-the-gaps.md) | `kaleidoscope`, `generative`, `style` |
| 2026-09-30 | `WSW-20260930-019` | implemented | [Engraving motifs: Haeckel plates cut into organisms](2026/2026-09-30-kaleidoscope-engraving-motifs.md) | `kaleidoscope`, `motifs`, `assets`, `generative` |
| 2026-09-30 | `WSW-20260930-018` | implemented | [Kaleidoscope: hatched, organic shapes in the drawn pattern generator](2026/2026-09-30-kaleidoscope-hatched-organic-shapes.md) | `kaleidoscope`, `generative`, `style` |
| 2026-09-30 | `WSW-20260930-017` | implemented | [Kaleidoscope: use a random set of ten motifs, not the whole folder](2026/2026-09-30-kaleidoscope-motif-selection-cap.md) | `kaleidoscope`, `motifs`, `interface` |
| 2026-09-30 | `WSW-20260930-016` | implemented | [Kaleidoscope: remembered setup and a default motif folder](2026/2026-09-30-kaleidoscope-remembered-setup.md) | `kaleidoscope`, `interface`, `motifs` |
| 2026-09-30 | `WSW-20260930-015` | implemented | [Kaleidoscope: auto-fit no longer overwrites typed numbers](2026/2026-09-30-kaleidoscope-non-destructive-autofit.md) | `kaleidoscope`, `interface`, `bounds` |
| 2026-09-30 | `WSW-20260930-014` | implemented | [Realistic nature motifs and deeper motif rings](2026/2026-09-30-realistic-nature-motifs.md) | `kaleidoscope`, `motifs`, `assets`, `generative` |
| 2026-09-30 | `WSW-20260930-013` | implemented | [Kaleidoscope: no cap on source size or typed bounds](2026/2026-09-30-kaleidoscope-uncapped-sizes.md) | `kaleidoscope`, `interface`, `bounds` |
| 2026-09-30 | `WSW-20260930-012` | implemented | [Kaleidoscope: zoom and pan the preview like the main converter](2026/2026-09-30-kaleidoscope-preview-zoom-pan.md) | `kaleidoscope`, `preview`, `interface` |
| 2026-09-30 | `WSW-20260930-011` | implemented | [Nature motif library for the kaleidoscope generator](2026/2026-09-30-nature-motif-library.md) | `kaleidoscope`, `motifs`, `assets`, `tooling` |
| 2026-09-30 | `WSW-20260930-010` | implemented | [Kaleidoscope: natural PNG motifs as the source of pattern diversity](2026/2026-09-30-kaleidoscope-natural-motifs.md) | `kaleidoscope`, `generative`, `motifs`, `raster` |
| 2026-09-30 | `WSW-20260930-009` | implemented | [Kaleidoscope: seeds choose a design, not just its phases](2026/2026-09-30-kaleidoscope-seed-diversity.md) | `kaleidoscope`, `generative`, `pattern-generator`, `seeds` |
| 2026-09-30 | `WSW-20260930-008` | implemented | [Kaleidoscope: complex multi-layer random patterns](2026/2026-09-30-kaleidoscope-complex-layers.md) | `kaleidoscope`, `generative`, `pattern-generator`, `density` |
| 2026-09-30 | `WSW-20260930-007` | implemented | [Kaleidoscope: engraving-density random patterns](2026/2026-09-30-kaleidoscope-engraving-density.md) | `kaleidoscope`, `generative`, `pattern-generator`, `density` |
| 2026-09-30 | `WSW-20260930-006` | implemented | [Kaleidoscope: deterministic random-pattern generator](2026/2026-09-30-kaleidoscope-random-pattern-generator.md) | `kaleidoscope`, `generative`, `pattern-generator`, `interface` |
| 2026-09-30 | `WSW-20260930-005` | implemented | [Kaleidoscope: typed printable bounds and a draggable image](2026/2026-09-30-kaleidoscope-typed-bounds-and-draggable-image.md) | `kaleidoscope`, `bounds`, `dragging`, `interface` |
| 2026-09-30 | `WSW-20260930-004` | implemented | [Add the Kaleidoscope Converter app](2026/2026-09-30-kaleidoscope-converter.md) | `kaleidoscope`, `raster`, `tracing`, `application`, `design` |
| 2026-09-30 | `WSW-20260930-003` | implemented | [Default to outlines only and fill only genuinely closed loops](2026/2026-09-30-outlines-only-default-and-closed-fill-regions.md) | `infill`, `correctness`, `defaults`, `fill-regions` |
| 2026-09-30 | `WSW-20260930-002` | implemented | [Keep pen-down bridging off by default and tag generated fill trails](2026/2026-09-30-tag-fill-trails-for-bridging.md) | `infill`, `bridge`, `pen-up`, `correctness`, `preview` |
| 2026-09-30 | `WSW-20260930-001` | implemented | [Calibrate the bed ratio from the measured A-index spacing](2026/2026-09-30-calibrated-bed-ratio.md) | `theta`, `kinematics`, `a-axis`, `calibration`, `registration`, `drift` |
| 2026-09-30 | `RPSW-20260930-004` | implemented | [Require a homed frame before the park macro moves](../rp23cnc-software/2026/2026-09-30-park-macro-requires-homed-frame.md) | `iosender`, `macro`, `p116`, `p111`, `park`, `g53`, `soft-limit`, `homing`, `safety`, `failed-approach` |
| 2026-09-30 | `RPSW-20260930-003` | implemented | [Add a manual pen-up-to-lift-home and park macro](../rp23cnc-software/2026/2026-09-30-manual-pen-up-and-park-macro.md) | `iosender`, `macro`, `p116`, `p115`, `lift-home`, `gp2`, `park`, `g53`, `service` |
| 2026-09-29 | `WSW-20260929-003` | implemented | [Re-derive the reach radius and give it a registration-drift margin](2026/2026-09-29-reach-radius-re-derived-with-drift-margin.md) | `converter`, `clipping`, `soft-limit`, `reachable-area`, `g54`, `alarm-2` |
| 2026-09-29 | `WSW-20260929-002` | implemented | [Auto-fit to the bed, and fill that follows the final scale](2026/2026-09-29-auto-fit-and-scale-aware-fill-cache.md) | `converter`, `usability`, `scale`, `reach`, `fill`, `cache` |
| 2026-09-29 | `WSW-20260929-001` | implemented | [Fill bed sizing and recentring for the fit actions](2026/2026-09-29-fill-bed-and-recenter-fits.md) | `converter`, `usability`, `scale`, `reach`, `placement` |
| 2026-09-29 | `RPSW-20260929-003` | implemented | [Define the level-1 system decomposition](../rp23cnc-software/2026/2026-09-29-level-1-system-decomposition.md) | `system-architecture`, `systems-integration`, `interfaces`, `documentation`, `project-management` |
| 2026-09-29 | `RPSW-20260929-002` | verified | [F-05A: the commissioned GP27/PRB pen-transition acknowledgement passed](../rp23cnc-software/2026/2026-09-29-f-05a-gp27-prb-handshake-verified.md) | `p115`, `gp27`, `prb`, `handshake`, `f-05a`, `commissioning` |
| 2026-09-28 | `WSW-20260928-002` | implemented | [Call out over-scale artwork and out-of-date previews](2026/2026-09-28-call-out-overscale-artwork-and-stale-previews.md) | `converter`, `usability`, `scale`, `reach`, `clipping`, `preview` |
| 2026-09-28 | `WSW-20260928-001` | implemented | [Automatic fill source and an intuitive settings layout](2026/2026-09-28-automatic-fill-and-settings-regroup.md) | `converter`, `usability`, `fill`, `hatch`, `line-art`, `settings-layout` |
| 2026-09-27 | `WSW-20260927-008` | implemented | [Restore the fixed-dwell default until F-05A passes](2026/2026-09-27-restore-dwell-default-until-f05a.md) | `converter`, `gp27`, `p115`, `error-39`, `f-05a`, `pen-dwell` |
| 2026-09-27 | `WSW-20260927-007` | implemented | [Drag the artwork on the bed to place it](2026/2026-09-27-drag-artwork-placement.md) | `converter`, `preview`, `placement`, `bed`, `drag`, `g54` |
| 2026-09-27 | `WSW-20260927-006` | implemented | [Show keep-down connectors in the preview](2026/2026-09-27-preview-keep-down-connectors.md) | `converter`, `preview`, `infill`, `serpentine`, `pen-cycle` |
| 2026-09-27 | `WSW-20260927-005` | implemented | [Chain line-family infill passes instead of lifting between them](2026/2026-09-27-chain-line-family-infill-passes.md) | `converter`, `infill`, `hatch`, `pen-cycle`, `serpentine`, `print-time` |
| 2026-09-27 | `WSW-20260927-004` | implemented | [Draw the gantry reach in the preview and report the artwork radius](2026/2026-09-27-preview-machine-reach-guide.md) | `converter`, `preview`, `gantry-reach`, `scaling`, `soft-limit`, `g54` |
| 2026-09-27 | `WSW-20260927-003` | implemented | [Apply the fill bleed margin by pulling back clipped passes](2026/2026-09-27-apply-fill-margin-by-pull-back.md) | `converter`, `fill`, `hatch`, `inset`, `clipping`, `correctness` |
| 2026-09-27 | `WSW-20260927-002` | implemented | [Accelerate fill generation with a polygon spatial index](2026/2026-09-27-speed-up-fill-region-with-spatial-index.md) | `converter`, `performance`, `fill`, `hatch`, `spatial-index`, `svg` |
| 2026-09-27 | `WSW-20260927-001` | implemented | [Resolve inherited SVG presentation attributes](2026/2026-09-27-resolve-inherited-svg-presentation-attributes.md) | `converter`, `svg`, `style-inheritance`, `shading`, `hatch`, `fill`, `line-art` |
| 2026-09-27 | `RPSW-20260927-002` | implemented | [Add a lift-and-continue recover mode to the P115 handshake](../rp23cnc-software/2026/2026-09-27-add-p115-recover-mode.md) | `p115`, `gp27`, `handshake`, `error-39`, `recover`, `f-05a` |
| 2026-09-27 | `RPSW-20260927-001` | implemented | [Parameterize the P115 handshake bounds and add a warn-only mode](../rp23cnc-software/2026/2026-09-27-parameterize-p115-bounds-and-warn-mode.md) | `p115`, `gp27`, `handshake`, `error-39`, `f-05a`, `warn-only` |
| 2026-09-26 | `WSW-20260926-002` | implemented | [Cap the drawable radius at the gantry's reach](2026/2026-09-26-cap-drawable-radius-to-gantry-reach.md) | `converter`, `clipping`, `soft-limit`, `reachable-area`, `bed` |
| 2026-09-26 | `WSW-20260926-001` | implemented | [Restore the generated pen-down path in the preview](2026/2026-09-26-restore-pen-down-preview-path.md) | `converter`, `preview`, `gcode`, `pen-down` |
| 2026-09-25 | `WSW-20260925-004` | implemented | [Add a single-centerline text SVG generator and Constitution preamble sample](2026/2026-09-25-add-single-line-text-svg-generator.md) | `converter`, `svg`, `hershey`, `single-line`, `text`, `sample` |
| 2026-09-25 | `WSW-20260925-003` | implemented | [Park the toolhead off the bed at program end](2026/2026-09-25-park-off-bed-at-program-end.md) | `converter`, `parking`, `g53`, `program-end` |
| 2026-09-25 | `WSW-20260925-002` | implemented | [Lower the pen-down dwell default to 2500 ms](2026/2026-09-25-lower-pen-down-dwell.md) | `converter`, `pen-dwell` |
| 2026-09-25 | `WSW-20260925-001` | implemented | [Default the GP27 handshake on](2026/2026-09-25-default-gp27-handshake.md) | `converter`, `gp27`, `handshake` |
| 2026-09-25 | `RPSW-20260925-009` | implemented | [Full retract the pen to GP2 at program end](../rp23cnc-software/2026/2026-09-25-full-retract-at-program-end.md) | `toolhead`, `full-retract`, `gp28`, `aux0`, `program-end`, `converter` |
| 2026-09-24 | `WSW-20260924-015` | implemented | [Show the artwork alone in the preview](2026/2026-09-24-clean-preview-artwork-only.md) | `converter`, `preview`, `polar` |
| 2026-09-24 | `WSW-20260924-014` | implemented | [Fill wide strokes instead of outlining thin ones](2026/2026-09-24-fill-wide-strokes-instead-of-outlining-thin.md) | `converter`, `stroke`, `fill`, `pen-width` |
| 2026-09-24 | `WSW-20260924-013` | implemented | [Give the program's first pen-down a cold-seek dwell](2026/2026-09-24-first-pen-down-cold-seek-dwell.md) | `converter`, `pen-dwell`, `cold-seek`, `gp2`, `first-plot` |
| 2026-09-24 | `WSW-20260924-012` | implemented | [Fix stroke-only elements being treated as invisible](2026/2026-09-24-fix-stroke-only-element-visibility.md) | `visibility`, `stroke`, `regression` |
| 2026-09-24 | `WSW-20260924-011` | implemented | [Restore manual-only preview refresh](2026/2026-09-24-restore-manual-preview-refresh.md) | `preview`, `shading`, `fill-pattern`, `ux` |
| 2026-09-24 | `WSW-20260924-010` | implemented | [Inset infill away from polygon boundaries](2026/2026-09-24-inset-infill-away-from-boundaries.md) | `infill`, `inset`, `boundary`, `correctness` |
| 2026-09-24 | `WSW-20260924-009` | implemented | [Drop sub-pen-width infill fragments](2026/2026-09-24-drop-sub-pen-width-infill-fragments.md) | `infill`, `pen-cycle`, `sliver`, `performance` |
| 2026-09-24 | `WSW-20260924-008` | implemented | [Subdivide polar moves linearly so A-axis-dominant lines stay straight](2026/2026-09-24-straighten-a-axis-polar-lines.md) | `polar`, `subdivision`, `straightness`, `a-axis` |
| 2026-09-24 | `WSW-20260924-007` | implemented | [Keep the pen down only between infill trails, never across shape outlines](2026/2026-09-24-bridge-only-between-infill-trails.md) | `infill`, `pen-up`, `bridge`, `correctness` |
| 2026-09-24 | `WSW-20260924-006` | implemented | [Fix fill leak and skip invisible white paths](2026/2026-09-24-fix-fill-leak-and-skip-white-paths.md) | `fill`, `correctness`, `point-in-polygon`, `invisibility` |
| 2026-09-24 | `WSW-20260924-005` | implemented | [Generate fill at on-paper resolution when the artwork is scaled down](2026/2026-09-24-fill-at-on-paper-resolution.md) | `performance`, `fill`, `scale`, `shading` |
| 2026-09-24 | `WSW-20260924-004` | implemented | [Eliminate duplicate theta planning during contour ordering](2026/2026-09-24-eliminate-duplicate-theta-planning.md) | `performance`, `theta`, `planner` |
| 2026-09-24 | `WSW-20260924-003` | implemented | [Tame cell-lattice fill density and fix triangular lattice over-generation](2026/2026-09-24-tame-cell-lattice-fill-density.md) | `shading`, `fill-pattern`, `performance`, `lattice` |
| 2026-09-24 | `WSW-20260924-002` | superseded | [Rebuild the preview when the fill pattern or raster shading changes (superseded)](2026/2026-09-24-refresh-preview-on-fill-pattern-change.md) | `preview`, `shading`, `fill-pattern`, `ux` |
| 2026-09-24 | `WSW-20260924-001` | implemented | [Speed up the parse/preview pipeline by removing duplicate theta candidates](2026/2026-09-24-speed-up-theta-planning.md) | `performance`, `theta`, `preview` |
| 2026-09-23 | `WSW-20260923-004` | implemented | [Add a curve-roundness test sample](2026/2026-09-23-add-curve-roundness-test-sample.md) | `sample`, `gcode`, `curve-flattening` |
| 2026-09-23 | `WSW-20260923-003` | implemented | [Set converter defaults for the installed toolhead](2026/2026-09-23-converter-defaults-for-toolhead.md) | `gcode`, `pen-plot`, `defaults`, `toolhead` |
| 2026-09-23 | `WSW-20260923-002` | implemented | [Subdivide draw moves so bed rotation traces straight lines](2026/2026-09-23-subdivide-polar-draw-moves.md) | `gcode`, `theta`, `polar`, `geometry` |
| 2026-09-23 | `WSW-20260923-001` | implemented | [Draw stroke centerlines by default instead of outlining the stroke width](2026/2026-09-23-draw-stroke-centerlines-by-default.md) | `gcode`, `pen-plot`, `performance` |
| 2026-09-22 | `WSW-20260922-002` | implemented | [File outstanding working-tree artifacts into the repository](2026/2026-09-22-file-outstanding-working-tree-artifacts.md) | `repository-hygiene`, `evidence`, `samples` |
| 2026-09-22 | `WSW-20260922-001` | implemented | [Ignore local tooling and build-scratch directories](2026/2026-09-22-ignore-local-tooling-and-build-scratch.md) | `repository-hygiene`, `tooling`, `commit-workflow` |
| 2026-09-22 | `RPSW-20260922-005` | implemented | [Route E-09E runtime through service UART](../rp23cnc-software/2026/2026-09-22-route-e09e-through-service-uart.md) | `e-09e`, `uart`, `usb-to-ttl`, `power-safety` |
| 2026-09-22 | `RPSW-20260922-004` | implemented | [Make E-09E pulse duration adjustable](../rp23cnc-software/2026/2026-09-22-make-e09e-pulse-duration-adjustable.md) | `e-09e`, `n20`, `pulse-duration`, `safety` |
| 2026-09-22 | `RPSW-20260922-003` | implemented | [Add E-09E installed-pen scale pulse check](../rp23cnc-software/2026/2026-09-22-add-e09e-pen-scale-pulse-check.md) | `cs1238`, `n20`, `kitchen-scale`, `e-09e`, `pen-pressure` |
| 2026-09-22 | `RPSW-20260922-001` | implemented | [Stage E-09C CS1238 force profile](../rp23cnc-software/2026/2026-09-22-stage-e09c-cs1238-force-profile.md) | `cs1238`, `e-09c`, `force-profile`, `pen-pressure`, `calibration` |
| 2026-09-21 | `WINSW-20260921-002` | implemented | [Add known-mass force-direction projection](2026/2026-09-21-add-known-mass-force-direction-projection.md) | `cs1238`, `known-mass`, `force-direction`, `pen-force`, `calibration`, `e-09c` |
| 2026-09-21 | `RP23CNC-20260921-007` | implemented | [Add bounded GP27 toolhead-ready wait](../rp23cnc-software/2026/2026-09-21-add-bounded-gp27-toolhead-wait.md) | `gp27`, `prb`, `m3-m5`, `pen-ready`, `synchronization`, `f-05a` |
| 2026-09-19 | `RPSW-20260919-001` | implemented | [Add Pico 2 dual-sensor DAQ firmware](../rp23cnc-software/2026/2026-09-19-add-pico2-dual-sensor-daq-firmware.md) | `pico2`, `cs1238`, `ina101`, `force-calibration`, `raw-data` |
| 2026-09-15 | `HW-20260915-001` | planned | [Plan Pico 2 dual-sensor calibration DAQ](../hardware/2026/2026-09-15-plan-pico2-dual-sensor-calibration-daq.md) | `pico2`, `cs1238`, `ina101`, `strain-gauge`, `force-calibration`, `testing` |
| 2026-09-11 | `WSW-20260911-001` | implemented | [Add Ontoly investigation prompt](2026/2026-09-11-add-ontoly-investigation-prompt.md) | `ontoly`, `architecture`, `impact-analysis`, `agent-workflow` |
| 2026-09-08 | `WSW-20260908-001` | implemented | [Calibrate the preview motion-time estimate](2026/2026-09-08-calibrate-preview-motion-estimate.md) | `preview`, `timing`, `m-06`, `calibration` |
| 2026-09-07 | `HW-20260907-002` | verified | [Verify converter motion and guarded X/Y envelope](../hardware/2026/2026-09-07-verify-converter-motion-and-guarded-xy-envelope.md) | `m-03`, `m-06`, `m-07`, `soft-limits`, `g54`, `xya` |
| 2026-09-06 | `WINSW-20260906-001` | implemented | [Center G54 output and correct the M-06 sample](2026/2026-09-06-center-g54-output-and-correct-m06-sample.md) | `g54`, `coordinates`, `parking`, `m-06`, `a-axis` |
| 2026-09-05 | `WSW-20260905-007` | implemented | [Share the preview motion plan](2026/2026-09-05-share-preview-motion-plan.md) | `preview`, `performance`, `motion-planning` |
| 2026-09-05 | `WSW-20260905-006` | implemented | [Make the production preview safe and complete](2026/2026-09-05-production-preview-safety.md) | `preview`, `gcode`, `validation`, `safety`, `iosender` |
| 2026-09-05 | `WSW-20260905-005` | implemented | [Consolidate current documentation ownership](2026/2026-09-05-consolidate-current-documentation.md) | `documentation`, `consolidation`, `source-of-truth`, `grblhal`, `toolhead` |
| 2026-09-05 | `WSW-20260905-004` | implemented | [Make converter programs self-contained for ioSender](2026/2026-09-05-self-contained-iosender-program-contract.md) | `iosender`, `grblhal`, `gcode`, `m3`, `m5`, `z-axis` |
| 2026-09-05 | `WSW-20260905-003` | implemented | [Record ioSender-to-converter compatibility review](2026/2026-09-05-iosender-converter-compatibility-review.md) | `iosender`, `grblhal`, `gcode`, `p100`, `integration-review` |
| 2026-09-05 | `WSW-20260905-002` | implemented | [Implement radius-aware A-axis feed for drawing](2026/2026-09-05-radius-aware-a-feed-requirement.md) | `theta`, `a-axis`, `tangential-speed`, `radius`, `feed-planning` |
| 2026-09-04 | `WSW-20260904-001` | implemented | [Move pen/TMAG XY offset ownership to P100](2026/2026-09-04-remove-converter-tool-offset.md) | `coordinate-frames`, `tool-offset`, `p100`, `g54` |
| 2026-09-03 | `RPSW-20260903-008` | implemented | [Add Opto-Isolation Presentation Slide](../rp23cnc-software/2026/2026-09-03-add-opto-isolation-presentation-slide.md) | `presentation`, `opto-isolation`, `wiring`, `p100` |
| 2026-09-02 | `RPSW-20260902-007` | implemented | [Full-Bleed Opening Slide Image](../rp23cnc-software/2026/2026-09-02-full-bleed-opening-slide-image.md) | `presentation`, `title-slide`, `toolhead` |
| 2026-09-02 | `RPSW-20260902-006` | implemented | [Refresh Summer Presentation Opening Render](../rp23cnc-software/2026/2026-09-02-refresh-summer-presentation-opening-render.md) | `presentation`, `toolhead`, `summer-progress` |
| 2026-09-02 | `RPSW-20260902-005` | implemented | [Expand P100 Presentation to Full Slide](../rp23cnc-software/2026/2026-09-02-expand-p100-presentation-to-full-slide.md) | `presentation`, `p100`, `interaction`, `layout` |
| 2026-09-02 | `RPSW-20260902-004` | implemented | [Align P100 Presentation Detail States](../rp23cnc-software/2026/2026-09-02-align-p100-presentation-detail-states.md) | `presentation`, `p100`, `interaction`, `correction` |
| 2026-09-02 | `RPSW-20260902-003` | implemented | [Add P100 Presentation Interaction](../rp23cnc-software/2026/2026-09-02-add-p100-presentation-interaction.md) | `presentation`, `p100`, `interaction`, `toolhead` |
| 2026-09-02 | `RPSW-20260902-002` | implemented | [Add Summer Progress Presentation](../rp23cnc-software/2026/2026-09-02-add-summer-progress-presentation.md) | `presentation`, `summer-progress`, `p100`, `toolhead`, `force-control` |
| 2026-09-02 | `RPSW-20260902-001` | implemented | [Add Current System Data Flow Chart](../rp23cnc-software/2026/2026-09-02-current-system-data-flow.md) | `data-flow`, `system-architecture`, `plotting`, `p100`, `toolhead`, `safety` |
| 2026-08-28 | `WSW-20260828-001` | implemented | [Establish sequential agent execution policy](2026/2026-08-28-agent-execution-policy.md) | `agent-workflow`, `token-efficiency`, `quality`, `project-policy` |
| 2026-08-14 | `RPSW-20260814-006` | implemented | [Document ioSender in the system overview](../rp23cnc-software/2026/2026-08-14-document-iosender-in-system-overview.md) | `iosender`, `system-overview`, `gcode` |
| 2026-07-04 | `WSW-20260704-001` | implemented | [Project Management Overview HTML](2026/2026-07-04-project-management-overview-html.md) | `project-management`, `dashboard`, `documentation`, `navigation` |
| 2026-06-07 | `WSW-20260607-006` | verified | [Animated Pen-Up Travel](2026/2026-06-07-animated-pen-up-travel.md) | `preview`, `playback`, `travel`, `simulation` |
| 2026-06-07 | `WSW-20260607-005` | verified | [Preview Cancellation](2026/2026-06-07-preview-cancellation.md) | `preview`, `cancellation`, `threading`, `safety` |
| 2026-06-07 | `WSW-20260607-004` | verified | [Single-File Engineering Topic Index](2026/2026-06-07-single-file-engineering-topic-index.md) | `engineering-log`, `topic-index`, `navigation`, `single-source` |
| 2026-06-07 | `WSW-20260607-003` | verified | [Documentation Navigation and Index Automation](2026/2026-06-07-documentation-navigation-and-index-automation.md) | `documentation`, `navigation`, `automation`, `maintainability` |
| 2026-06-07 | `WSW-20260607-002` | verified | [Continuous Maintainability Policy](2026/2026-06-07-continuous-maintainability-policy.md) | `maintainability`, `technical-debt`, `documentation`, `project-policy` |
| 2026-06-07 | `WSW-20260607-001` | verified | [Preview Build Progress and Responsive Processing](2026/2026-06-07-preview-build-progress.md) | `preview`, `ui`, `threading`, `progress`, `elapsed-time` |
<!-- END GENERATED CHANGES -->

See the [combined change index](../INDEX.md).

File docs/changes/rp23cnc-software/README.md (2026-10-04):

# RP23CNC Software Changes

Scope: RP23CNC/grblHAL builds, controller configuration, plugins, settings,
transport, and other machine-side embedded software including the pen-pressure
controller.

Newest changes appear first.

<!-- BEGIN GENERATED CHANGES -->
| Date | ID | Status | Summary | Tags |
|---|---|---|---|---|
| 2026-10-04 | `WSW-20261004-001` | implemented | [Default the GP27 handshake and recover options on](../windows-software/2026/2026-10-04-default-gp27-handshake-and-recover.md) | `converter`, `gp27`, `p115`, `handshake`, `pen-dwell`, `defaults` |
| 2026-10-02 | `RPSW-20261002-001` | implemented | [Raise the M5 clearance pulse to 70 ms](2026/2026-10-02-raise-m5-clearance-to-70ms.md) | `m5`, `pen-clear`, `clearance`, `toolhead`, `drag` |
| 2026-10-01 | `RPSW-20261001-002` | verified | [Axis-centre correction in P100: the registered origin moves +1.25 mm in X](2026/2026-10-01-axis-centre-correction.md) | `grblhal`, `macro`, `p100`, `registration`, `calibration`, `drift` |
| 2026-10-01 | `RPSW-20261001-001` | verified | [Lower the A-axis maximum rate to 20000 motor deg/min](2026/2026-10-01-a-axis-rate-limit-20000.md) | `grblhal`, `settings`, `theta`, `drift`, `safety` |
| 2026-09-30 | `WSW-20260930-001` | implemented | [Calibrate the bed ratio from the measured A-index spacing](../windows-software/2026/2026-09-30-calibrated-bed-ratio.md) | `theta`, `kinematics`, `a-axis`, `calibration`, `registration`, `drift` |
| 2026-09-30 | `RPSW-20260930-004` | implemented | [Require a homed frame before the park macro moves](2026/2026-09-30-park-macro-requires-homed-frame.md) | `iosender`, `macro`, `p116`, `p111`, `park`, `g53`, `soft-limit`, `homing`, `safety`, `failed-approach` |
| 2026-09-30 | `RPSW-20260930-003` | implemented | [Add a manual pen-up-to-lift-home and park macro](2026/2026-09-30-manual-pen-up-and-park-macro.md) | `iosender`, `macro`, `p116`, `p115`, `lift-home`, `gp2`, `park`, `g53`, `service` |
| 2026-09-30 | `RPSW-20260930-002` | implemented | [Widen the 40 g pen-force band back to ±15 g](2026/2026-09-30-widen-pen-force-band-to-15g.md) | `toolhead`, `force-control`, `pen-force`, `calibration`, `safety` |
| 2026-09-30 | `RPSW-20260930-001` | implemented | [Set the pen force target to 40 g with a ±10 g band](2026/2026-09-30-set-pen-force-40g-band-10g.md) | `toolhead`, `force-control`, `pen-force`, `calibration`, `safety` |
| 2026-09-29 | `WSW-20260929-003` | implemented | [Re-derive the reach radius and give it a registration-drift margin](../windows-software/2026/2026-09-29-reach-radius-re-derived-with-drift-margin.md) | `converter`, `clipping`, `soft-limit`, `reachable-area`, `g54`, `alarm-2` |
| 2026-09-29 | `RPSW-20260929-005` | implemented | [Revert the pen force target to 45 g with a ±15 g band](2026/2026-09-29-revert-pen-force-target-to-45g.md) | `toolhead`, `force-control`, `pen-force`, `revert` |
| 2026-09-29 | `RPSW-20260929-004` | superseded | [Lower the pen force target to 38 g with a ±10 g band](2026/2026-09-29-lower-pen-force-target-to-38g.md) | `toolhead`, `force-control`, `pen-force`, `calibration`, `safety` |
| 2026-09-29 | `RPSW-20260929-003` | implemented | [Define the level-1 system decomposition](2026/2026-09-29-level-1-system-decomposition.md) | `system-architecture`, `systems-integration`, `interfaces`, `documentation`, `project-management` |
| 2026-09-29 | `RPSW-20260929-002` | verified | [F-05A: the commissioned GP27/PRB pen-transition acknowledgement passed](2026/2026-09-29-f-05a-gp27-prb-handshake-verified.md) | `p115`, `gp27`, `prb`, `handshake`, `f-05a`, `commissioning` |
| 2026-09-29 | `RPSW-20260929-001` | implemented | [Hold the published contact-ready level through hold corrections](2026/2026-09-29-hold-contact-ready-hysteresis.md) | `toolhead`, `gp27`, `contact-ready`, `handshake`, `p115`, `f-05a` |
| 2026-09-28 | `RPSW-20260928-001` | verified | [Direct host-to-controller Ethernet link at 10 Mbps](2026/2026-09-28-direct-ethernet-link.md) | `grblhal`, `ethernet`, `w5500`, `network`, `telnet`, `static-ip` |
| 2026-09-27 | `WSW-20260927-008` | implemented | [Restore the fixed-dwell default until F-05A passes](../windows-software/2026/2026-09-27-restore-dwell-default-until-f05a.md) | `converter`, `gp27`, `p115`, `error-39`, `f-05a`, `pen-dwell` |
| 2026-09-27 | `RPSW-20260927-002` | implemented | [Add a lift-and-continue recover mode to the P115 handshake](2026/2026-09-27-add-p115-recover-mode.md) | `p115`, `gp27`, `handshake`, `error-39`, `recover`, `f-05a` |
| 2026-09-27 | `RPSW-20260927-001` | implemented | [Parameterize the P115 handshake bounds and add a warn-only mode](2026/2026-09-27-parameterize-p115-bounds-and-warn-mode.md) | `p115`, `gp27`, `handshake`, `error-39`, `f-05a`, `warn-only` |
| 2026-09-25 | `RPSW-20260925-009` | implemented | [Full retract the pen to GP2 at program end](2026/2026-09-25-full-retract-at-program-end.md) | `toolhead`, `full-retract`, `gp28`, `aux0`, `program-end`, `converter` |
| 2026-09-25 | `RPSW-20260925-008` | implemented | [Widen the force-hold band to ±15 g (30-60 g)](2026/2026-09-25-widen-hold-band-30-60g.md) | `toolhead`, `force`, `hold-band`, `high-speed` |
| 2026-09-25 | `RPSW-20260925-007` | implemented | [Guarantee a GP27 inactive interval on every pen-command transition](2026/2026-09-25-gp27-transition-low-window.md) | `toolhead`, `gp27`, `handshake`, `p115` |
| 2026-09-25 | `RPSW-20260925-006` | implemented | [Auto-clear a latched fault when the pen-up command is held](2026/2026-09-25-auto-clear-fault-on-pen-up.md) | `toolhead`, `fault`, `recovery`, `uart` |
| 2026-09-25 | `RPSW-20260925-005` | implemented | [Move the hold band to 35-55 g](2026/2026-09-25-raise-hold-band-35-55g.md) | `toolhead`, `force`, `hold-band` |
| 2026-09-25 | `RPSW-20260925-004` | implemented | [Raise the hard-force limit to 75 g](2026/2026-09-25-raise-hard-force-limit-75g.md) | `toolhead`, `force`, `hard-limit` |
| 2026-09-25 | `RPSW-20260925-003` | implemented | [Enable the GP27 normal-print status](2026/2026-09-25-enable-gp27-normal-print-status.md) | `toolhead`, `gp27`, `handshake`, `p115` |
| 2026-09-25 | `RPSW-20260925-002` | implemented | [Recover from CS1238 implausible-reading bursts](2026/2026-09-25-recover-from-implausible-readings.md) | `toolhead`, `cs1238`, `recovery`, `fault` |
| 2026-09-25 | `RPSW-20260925-001` | verified | [Accept T-01H and enable the pen-clear status](2026/2026-09-25-accept-t-01h-pen-clear.md) | `toolhead`, `pen-clear`, `t-01h` |
| 2026-09-24 | `WSW-20260924-013` | implemented | [Give the program's first pen-down a cold-seek dwell](../windows-software/2026/2026-09-24-first-pen-down-cold-seek-dwell.md) | `converter`, `pen-dwell`, `cold-seek`, `gp2`, `first-plot` |
| 2026-09-24 | `RPSW-20260924-004` | implemented | [Raise the toolhead force envelope 5 g](2026/2026-09-24-raise-force-envelope-5g.md) | `toolhead`, `force`, `calibration` |
| 2026-09-24 | `RPSW-20260924-003` | implemented | [Bound the coarse seek step and auto-recover from hard-limit overshoot](2026/2026-09-24-bound-coarse-seek-and-recover-hard-limit.md) | `toolhead`, `force-control`, `hard-limit`, `recovery`, `seek` |
| 2026-09-24 | `RPSW-20260924-002` | implemented | [Report magnet detection instead of a compile flag in the `ready=[...]` field](2026/2026-09-24-fix-toolhead-gp27-telemetry-field.md) | `telemetry`, `magnetic-homing`, `e-18` |
| 2026-09-24 | `RPSW-20260924-001` | verified | [Enable the integrated toolhead magnetic commissioning gate](2026/2026-09-24-enable-magnetic-commissioning-gate.md) | `p100`, `magnetic-homing`, `e-18`, `m-08`, `commissioning` |
| 2026-09-23 | `WSW-20260923-003` | implemented | [Set converter defaults for the installed toolhead](../windows-software/2026/2026-09-23-converter-defaults-for-toolhead.md) | `gcode`, `pen-plot`, `defaults`, `toolhead` |
| 2026-09-23 | `RPSW-20260923-016` | implemented | [Widen the force-hold band to ±10 g and move relief to 15 g](2026/2026-09-23-widen-hold-band.md) | `t03`, `hold`, `force-band`, `reliability` |
| 2026-09-23 | `RPSW-20260923-015` | verified | [Invert the grblHAL spindle enable to match the toolhead input](2026/2026-09-23-invert-spindle-enable-for-toolhead.md) | `f05`, `m3m5`, `spindle`, `toolhead`, `polarity` |
| 2026-09-23 | `RPSW-20260923-014` | implemented | [Require a full filter window of implausible samples before faulting](2026/2026-09-23-raise-implausible-fault-streak.md) | `t02`, `sensor-health`, `reliability` |
| 2026-09-23 | `RPSW-20260923-013` | implemented | [Stabilize warm-seek travel and stop motor-driven sensor-noise faults](2026/2026-09-23-stabilize-warm-seek-travel.md) | `t02`, `contact-seek`, `latency`, `sensor-health`, `learning` |
| 2026-09-23 | `RPSW-20260923-012` | implemented | [Split the seek settle by proximity to the target](2026/2026-09-23-split-seek-settle.md) | `t02`, `contact-seek`, `latency` |
| 2026-09-23 | `RPSW-20260923-011` | implemented | [Reduce the M5 clearance air gap to about 1 mm](2026/2026-09-23-reduce-m5-clearance-air-gap.md) | `m5`, `clearance`, `performance` |
| 2026-09-23 | `RPSW-20260923-010` | implemented | [Widen the warm coarse-phase force gate](2026/2026-09-23-widen-warm-coarse-force-gate.md) | `t02`, `contact-seek`, `learning` |
| 2026-09-23 | `RPSW-20260923-009` | implemented | [Learn warm-seek travel to traverse it with coarse pulses](2026/2026-09-23-learn-warm-seek-travel.md) | `t02`, `contact-seek`, `performance`, `learning` |
| 2026-09-23 | `RPSW-20260923-008` | implemented | [Replace the two-touch seek with a single descend](2026/2026-09-23-replace-two-touch-with-single-descend.md) | `t02`, `contact-seek`, `performance`, `simplification` |
| 2026-09-23 | `RPSW-20260923-007` | implemented | [Reject implausible CS1238 conversions](2026/2026-09-23-reject-implausible-cs1238-samples.md) | `cs1238`, `force-control`, `false-fault`, `observability` |
| 2026-09-23 | `RPSW-20260923-006` | implemented | [Reduce the sensing settle to the measured 300 ms](2026/2026-09-23-reduce-settle-to-measured-300ms.md) | `settle`, `performance`, `force-control`, `t02` |
| 2026-09-23 | `RPSW-20260923-005` | implemented | [Add a one-pulse settle trace to E-09E](2026/2026-09-23-add-e09e-settle-trace.md) | `settle`, `characterization`, `observability`, `e09e` |
| 2026-09-23 | `RPSW-20260923-004` | implemented | [Add hysteresis to the urgent over-force relief](2026/2026-09-23-add-hysteresis-to-urgent-relief.md) | `t03`, `force-control`, `hold`, `hunting` |
| 2026-09-23 | `RPSW-20260923-003` | implemented | [Report urgent over-force relief activity in telemetry](2026/2026-09-23-report-urgent-relief-telemetry.md) | `observability`, `telemetry`, `force-control` |
| 2026-09-23 | `RPSW-20260923-002` | implemented | [Add bounded urgent over-force relief to the hold loop](2026/2026-09-23-add-urgent-over-force-relief.md) | `t03`, `force-control`, `hold`, `hard-limit` |
| 2026-09-23 | `RPSW-20260923-001` | implemented | [Clamp the hold band below the hard-force limit](2026/2026-09-23-clamp-hold-band-below-hard-limit.md) | `t02`, `force-control`, `hard-limit`, `safety-margin` |
| 2026-09-22 | `WSW-20260922-002` | implemented | [File outstanding working-tree artifacts into the repository](../windows-software/2026/2026-09-22-file-outstanding-working-tree-artifacts.md) | `repository-hygiene`, `evidence`, `samples` |
| 2026-09-22 | `WSW-20260922-001` | implemented | [Ignore local tooling and build-scratch directories](../windows-software/2026/2026-09-22-ignore-local-tooling-and-build-scratch.md) | `repository-hygiene`, `tooling`, `commit-workflow` |
| 2026-09-22 | `RPSW-20260922-034` | implemented | [Settle the home contact seek on settled force](2026/2026-09-22-settle-contact-seek-on-settled-force.md) | `t02`, `contact-seek`, `settle`, `cs1238`, `force-control` |
| 2026-09-22 | `RPSW-20260922-033` | implemented | [Record E-07B trace-settle tuning](2026/2026-09-22-record-e07b-trace-settle-tuning.md) | `hx711`, `e07b`, `bench-diagnostic`, `historical-evidence` |
| 2026-09-22 | `RPSW-20260922-032` | implemented | [Refresh Tare after Normal Pen Clear](2026/2026-09-22-tare-after-normal-clear.md) | `cs1238`, `tare`, `pen-clear`, `m3-m5` |
| 2026-09-22 | `RPSW-20260922-031` | implemented | [Trend-gate Force-hold Corrections](2026/2026-09-22-trend-gate-hold-corrections.md) | `cs1238`, `moving-average`, `force-control`, `stiction` |
| 2026-09-22 | `RPSW-20260922-030` | implemented | [Bound Trend Contact to a Usable Envelope](2026/2026-09-22-bound-trend-contact-envelope.md) | `cs1238`, `force-limit`, `contact-detection`, `safety` |
| 2026-09-22 | `RPSW-20260922-029` | implemented | [Re-acquire Contact after M5 Clearance](2026/2026-09-22-reacquire-contact-after-clear.md) | `cs1238`, `m3-m5`, `contact-detection`, `force-control` |
| 2026-09-22 | `RPSW-20260922-028` | implemented | [Confirm Contact by Trend](2026/2026-09-22-confirm-contact-trend.md) | `cs1238`, `contact-detection`, `moving-average`, `force-control` |
| 2026-09-22 | `RPSW-20260922-027` | implemented | [Extend Fine Force-Tune Budget](2026/2026-09-22-extend-fine-force-tune-budget.md) | `cs1238`, `n20`, `force-tune`, `safety` |
| 2026-09-22 | `RPSW-20260922-026` | implemented | [Tare After Lift-Home Release](2026/2026-09-22-tare-after-lift-home-release.md) | `cs1238`, `tare`, `lift-home`, `gp2` |
| 2026-09-22 | `RPSW-20260922-025` | implemented | [Add Two-Touch Home Approach](2026/2026-09-22-add-two-touch-home-approach.md) | `cs1238`, `force-control`, `n20`, `surface-touch` |
| 2026-09-22 | `RPSW-20260922-024` | implemented | [Bound Moving-Average Hold Pulses](2026/2026-09-22-bound-moving-average-hold-pulses.md) | `cs1238`, `force-hold`, `n20`, `safety` |
| 2026-09-22 | `RPSW-20260922-023` | implemented | [Tare Only After Home Retract](2026/2026-09-22-tare-after-home-retract.md) | `cs1238`, `tare`, `contact-seek` |
| 2026-09-22 | `RPSW-20260922-022` | implemented | [Add Fine Home Contact Approach](2026/2026-09-22-add-fine-home-contact-approach.md) | `contact-seek`, `pulse-timing`, `force-limit` |
| 2026-09-22 | `RPSW-20260922-021` | implemented | [Revise Home Contact-Seek Pacing](2026/2026-09-22-revise-home-contact-seek-pacing.md) | `contact-seek`, `pulse-timing`, `cs1238` |
| 2026-09-22 | `RPSW-20260922-020` | implemented | [Bound Home-Origin Contact Seek](2026/2026-09-22-bound-home-origin-contact-seek.md) | `contact-seek`, `cs1238`, `pen-pressure` |
| 2026-09-22 | `RPSW-20260922-019` | implemented | [Make integrated toolhead telemetry quiet by default](2026/2026-09-22-quiet-integrated-toolhead-telemetry.md) | `serial-monitor`, `telemetry`, `fault-diagnostics`, `cs1238` |
| 2026-09-22 | `RPSW-20260922-018` | implemented | [Set integrated force target to 35 g and limit to 60 g](2026/2026-09-22-set-integrated-force-target-35g-limit-60g.md) | `cs1238`, `force-target`, `hard-force-limit`, `supervised-bench` |
| 2026-09-22 | `RPSW-20260922-017` | verified | [Set integrated lift timeout to 3000 ms](2026/2026-09-22-set-integrated-lift-timeout-3000ms.md) | `gp2`, `lift-home`, `timeout` |
| 2026-09-22 | `RPSW-20260922-016` | implemented | [Match integrated lift drive to validated bench pulses](2026/2026-09-22-increase-integrated-lift-drive.md) | `motor-drive`, `gp2`, `supervised-bench` |
| 2026-09-22 | `RPSW-20260922-015` | implemented | [Correct integrated motor-direction polarity](2026/2026-09-22-correct-integrated-direction-polarity.md) | `motor-direction`, `gp2`, `supervised-bench` |
| 2026-09-22 | `RPSW-20260922-014` | implemented | [Enable the mechanical-preload supervised bench build](2026/2026-09-22-enable-mechanical-preload-bench-build.md) | `supervised-bench`, `mechanical-preload`, `moving-average-force-control` |
| 2026-09-22 | `RPSW-20260922-013` | implemented | [Stage mechanical-preload M3/M5 behavior](2026/2026-09-22-stage-mechanical-preload-m3m5.md) | `mechanical-preload`, `m3-m5`, `cs1238`, `pen-clearance` |
| 2026-09-22 | `RPSW-20260922-012` | implemented | [Add E-09F manual down setup pulse](2026/2026-09-22-add-e09f-manual-down-setup.md) | `e-09f`, `n20`, `pen-installation`, `manual-control` |
| 2026-09-22 | `RPSW-20260922-011` | implemented | [Delay E-09F air-gap telemetry](2026/2026-09-22-delay-e09f-air-gap-telemetry.md) | `e-09f`, `cs1238`, `pen-clear`, `settling` |
| 2026-09-22 | `RPSW-20260922-010` | implemented | [Add E-09F manual retract recovery](2026/2026-09-22-add-e09f-manual-retract-recovery.md) | `e-09f`, `n20`, `retract`, `recovery`, `safety` |
| 2026-09-22 | `RPSW-20260922-009` | implemented | [Fix E-09F release hard-limit fault](2026/2026-09-22-fix-e09f-release-hard-limit.md) | `e-09f`, `cs1238`, `pen-clear`, `fault-handling` |
| 2026-09-22 | `RPSW-20260922-008` | implemented | [Add E-09F guarded force-hold test](2026/2026-09-22-add-e09f-guarded-force-hold.md) | `e-09f`, `cs1238`, `force-hold`, `pen-clear`, `safety` |
| 2026-09-22 | `RPSW-20260922-007` | implemented | [Refine E-09E pulses and stage pen-clear candidate](2026/2026-09-22-refine-e09e-pulses-and-stage-pen-clear.md) | `e-09e`, `n20`, `pen-clear`, `pulse-duration`, `safety` |
| 2026-09-22 | `RPSW-20260922-006` | implemented | [Add E-09E Serial Monitor shortcuts](2026/2026-09-22-add-e09e-serial-monitor-shortcuts.md) | `e-09e`, `uart`, `arduino-ide`, `kitchen-scale`, `safety` |
| 2026-09-22 | `RPSW-20260922-005` | implemented | [Route E-09E runtime through service UART](2026/2026-09-22-route-e09e-through-service-uart.md) | `e-09e`, `uart`, `usb-to-ttl`, `power-safety` |
| 2026-09-22 | `RPSW-20260922-004` | implemented | [Make E-09E pulse duration adjustable](2026/2026-09-22-make-e09e-pulse-duration-adjustable.md) | `e-09e`, `n20`, `pulse-duration`, `safety` |
| 2026-09-22 | `RPSW-20260922-003` | implemented | [Add E-09E installed-pen scale pulse check](2026/2026-09-22-add-e09e-pen-scale-pulse-check.md) | `cs1238`, `n20`, `kitchen-scale`, `e-09e`, `pen-pressure` |
| 2026-09-22 | `RPSW-20260922-002` | implemented | [Replace E-09C profile with cap-free repeat](2026/2026-09-22-replace-e09c-cap-free-calibration.md) | `cs1238`, `e-09c`, `calibration`, `load-cell`, `pen-pressure` |
| 2026-09-22 | `RPSW-20260922-001` | implemented | [Stage E-09C CS1238 force profile](2026/2026-09-22-stage-e09c-cs1238-force-profile.md) | `cs1238`, `e-09c`, `force-profile`, `pen-pressure`, `calibration` |
| 2026-09-21 | `WINSW-20260921-002` | implemented | [Add known-mass force-direction projection](../windows-software/2026/2026-09-21-add-known-mass-force-direction-projection.md) | `cs1238`, `known-mass`, `force-direction`, `pen-force`, `calibration`, `e-09c` |
| 2026-09-21 | `WINSW-20260921-001` | implemented | [Add Pro Micro known-mass calibration application](../windows-software/2026/2026-09-21-add-pro-micro-known-mass-calibration-app.md) | `cs1238`, `calibration`, `known-mass`, `plotting` |
| 2026-09-21 | `RPSW-20260921-002` | implemented | [Migrate Integrated Toolhead to CS1238 Backend](2026/2026-09-21-migrate-integrated-toolhead-cs1238-backend.md) | `CS1238`, `load-cell`, `force-control`, `safety-gates` |
| 2026-09-21 | `RP23CNC-20260921-008` | implemented | [Add post-release pen-clear air-gap pulse](2026/2026-09-21-add-post-release-pen-clear-air-gap.md) | `pen-clear`, `air-gap`, `n20`, `cs1238`, `t-01h` |
| 2026-09-21 | `RP23CNC-20260921-007` | implemented | [Add bounded GP27 toolhead-ready wait](2026/2026-09-21-add-bounded-gp27-toolhead-wait.md) | `gp27`, `prb`, `m3-m5`, `pen-ready`, `synchronization`, `f-05a` |
| 2026-09-19 | `WINSW-20260919-001` | implemented | [Add guided force-calibration analysis workflow](../windows-software/2026/2026-09-19-add-guided-force-calibration-analysis.md) | `force-calibration`, `pico2`, `cs1238`, `ina101`, `plotting` |
| 2026-09-15 | `HW-20260915-001` | planned | [Plan Pico 2 dual-sensor calibration DAQ](../hardware/2026/2026-09-15-plan-pico2-dual-sensor-calibration-daq.md) | `pico2`, `cs1238`, `ina101`, `strain-gauge`, `force-calibration`, `testing` |
| 2026-09-13 | `HW-20260913-013` | planned | [Plan CS1238 force-sensor replacement](../hardware/2026/2026-09-13-plan-cs1238-force-sensor-replacement.md) | `toolhead`, `cs1238`, `hx711`, `load-cell`, `force-control`, `testing` |
| 2026-09-13 | `HW-20260913-011` | implemented | [Add E07B fine force-pulse control](../hardware/2026/2026-09-13-add-e07b-fine-force-pulse-control.md) | `n20`, `force-control`, `pulse-duration`, `e-07b` |
| 2026-09-13 | `HW-20260913-010` | verified | [Calibrate E07B N20 direction](../hardware/2026/2026-09-13-calibrate-e07b-n20-direction.md) | `n20`, `drv8833`, `direction`, `e-07b` |
| 2026-09-13 | `HW-20260913-009` | verified | [Repair DRV8833 output solder joint](../hardware/2026/2026-09-13-repair-drv8833-output-solder-joint.md) | `drv8833`, `n20`, `solder-repair`, `e-14c` |
| 2026-09-13 | `HW-20260913-008` | implemented | [Add manual historical E-05 step test](../hardware/2026/2026-09-13-add-manual-legacy-e05-steps.md) | `n20`, `drv8833`, `e-05`, `pulse-duration`, `diagnostics` |
| 2026-09-13 | `HW-20260913-007` | implemented | [Preserve historical E-05 motor test](../hardware/2026/2026-09-13-preserve-historical-e05-motor-test.md) | `n20`, `drv8833`, `e-05`, `regression-test` |
| 2026-09-13 | `HW-20260913-006` | implemented | [Extend E07B actuator pulse range](../hardware/2026/2026-09-13-extend-e07b-actuator-pulse-range.md) | `n20`, `toolhead`, `pulse-duration`, `diagnostics` |
| 2026-09-13 | `HW-20260913-005` | implemented | [Add DRV8833 loaded-fault telemetry](../hardware/2026/2026-09-13-add-drv8833-loaded-fault-telemetry.md) | `drv8833`, `fault`, `diagnostics`, `toolhead` |
| 2026-09-13 | `HW-20260913-004` | planned | [Isolate N20 output-connection failure](../hardware/2026/2026-09-13-isolate-n20-output-connection-failure.md) | `drv8833`, `n20`, `toolhead`, `diagnostics` |
| 2026-09-13 | `HW-20260913-003` | implemented | [Add isolated DRV8833 output meter mode](../hardware/2026/2026-09-13-add-isolated-drv8833-output-meter-mode.md) | `drv8833`, `toolhead`, `diagnostics`, `e-14c` |
| 2026-09-13 | `HW-20260913-002` | implemented | [Add non-motion DRV8833 meter mode](../hardware/2026/2026-09-13-add-nonmotion-drv8833-meter-mode.md) | `drv8833`, `toolhead`, `diagnostics`, `e-14c` |
| 2026-09-13 | `HW-20260913-001` | implemented | [Correct confirmed DRV8833 sleep/fault mapping](../hardware/2026/2026-09-13-correct-drv8833-sleep-fault-mapping.md) | `drv8833`, `toolhead`, `wiring`, `pen-pressure` |
| 2026-09-12 | `RPSW-20260912-001` | verified | [Record P113 unified registration command](2026/2026-09-12-record-p113-unified-registration.md) | `P113`, `P100`, `P111`, `homing`, `magnetic-registration`, `G54` |
| 2026-09-11 | `WSW-20260911-001` | implemented | [Add Ontoly investigation prompt](../windows-software/2026/2026-09-11-add-ontoly-investigation-prompt.md) | `ontoly`, `architecture`, `impact-analysis`, `agent-workflow` |
| 2026-09-11 | `RPSW-20260911-013` | implemented | [Retune P100 Q5 Raster Density](2026/2026-09-11-retune-p100-q5-raster.md) | `P100`, `Q5`, `raster`, `scan-feed`, `safety` |
| 2026-09-11 | `RPSW-20260911-012` | implemented | [Add P112 Outer-Index Survey](2026/2026-09-11-add-p112-outer-index-survey.md) | `P112`, `P100`, `A-axis`, `index-magnet`, `M-09`, `safety` |
| 2026-09-11 | `RPSW-20260911-011` | implemented | [Isolate P100 System Homing](2026/2026-09-11-isolate-p100-system-homing.md) | `P100`, `P111`, `homing`, `grblHAL`, `safety` |
| 2026-09-11 | `RPSW-20260911-010` | verified | [Add P110 Q5 First G38 Row Diagnostic](2026/2026-09-11-add-p110-q5-first-g38-row-diagnostic.md) | `P100`, `P110`, `Q5`, `G38`, `probe`, `diagnostic`, `safety` |
| 2026-09-11 | `RPSW-20260911-009` | verified | [Add P109 Q5 Combined Diagnostic](2026/2026-09-11-add-p109-q5-combined-diagnostic.md) | `P100`, `P109`, `Q5`, `diagnostic`, `handshake`, `raster`, `safety` |
| 2026-09-11 | `RPSW-20260911-008` | verified | [Add P108 Q5 Handshake Diagnostic](2026/2026-09-11-add-p108-q5-handshake-diagnostic.md) | `P100`, `P108`, `Q5`, `handshake`, `diagnostic`, `safety` |
| 2026-09-11 | `RPSW-20260911-007` | verified | [Add P107 Q5 Preposition Diagnostic](2026/2026-09-11-add-p107-q5-preposition-diagnostic.md) | `P100`, `P107`, `Q5`, `diagnostic`, `homing`, `safety` |
| 2026-09-11 | `RPSW-20260911-006` | verified | [Add P100 Q5 Centroid Survey](2026/2026-09-11-add-p100-q5-centroid-survey.md) | `P100`, `Q5`, `centroid`, `raster`, `safety` |
| 2026-09-11 | `RPSW-20260911-005` | implemented | [Add P106 Manual Magnetic Survey](2026/2026-09-11-add-p106-manual-magnetic-survey.md) | `P100`, `Q3`, `P106`, `magnetic-survey`, `safety` |
| 2026-09-11 | `RPSW-20260911-004` | implemented | [Record P100 Q3 Candidate Scan Parameters](2026/2026-09-11-record-p100-q3-candidate-parameters.md) | `P100`, `Q3`, `scan-feed`, `tool-offset`, `safety` |
| 2026-09-11 | `RPSW-20260911-003` | implemented | [Record P100 Q3 Candidate Scan Rectangle](2026/2026-09-11-record-p100-q3-candidate-rectangle.md) | `P100`, `Q3`, `scan-bounds`, `G53`, `safety` |
| 2026-09-11 | `RPSW-20260911-002` | verified | [Enable Isolated P100 Q2 X/Y Homing](2026/2026-09-11-enable-isolated-p100-q2-home.md) | `P100`, `homing`, `safety`, `grblHAL` |
| 2026-09-11 | `RPSW-20260911-001` | verified | [Verify P100 Q1 probe handshake](2026/2026-09-11-verify-p100-q1-probe-handshake.md) | `p100`, `q1`, `probe`, `gp27`, `safety` |
| 2026-09-10 | `RPSW-20260910-003` | verified | [Correct P100 installed Aux0 polarity](2026/2026-09-10-correct-p100-aux-polarity.md) | `p100`, `aux0`, `gp28`, `safety`, `macro` |
| 2026-09-10 | `RPSW-20260910-002` | verified | [Verify real-magnet PRB/G38 path](2026/2026-09-10-prb-g38-magnetic-path.md) | `p100`, `f-08`, `probe`, `g38`, `magnetic-homing`, `safety` |
| 2026-09-10 | `RPSW-20260910-001` | verified | [Record motor-inert P100 handshake evidence](2026/2026-09-10-record-motor-inert-p100-handshake.md) | `p100`, `magnetic-homing`, `e-18`, `f-08`, `safety` |
| 2026-09-09 | `RPSW-20260909-002` | implemented | [Add motor-inert P100 handshake diagnostic](2026/2026-09-09-add-motor-inert-p100-handshake-diagnostic.md) | `p100`, `magnetic-homing`, `f-08`, `e-18`, `safety` |
| 2026-09-09 | `RPSW-20260909-001` | implemented | [Add lift-home status to bounded actuator test](2026/2026-09-09-add-lift-home-status-to-bounded-actuator-test.md) | `toolhead`, `t-01g`, `lift-home`, `uart`, `commissioning` |
| 2026-09-09 | `HW-20260909-003` | implemented | [Document toolhead pen-mount mechanics](../hardware/2026/2026-09-09-document-toolhead-pen-mount-mechanics.md) | `toolhead`, `pen-mount`, `spring`, `mechanics`, `t-01` |
| 2026-09-09 | `HW-20260909-002` | planned | [Order faster toolhead actuator candidates](../hardware/2026/2026-09-09-order-faster-toolhead-actuator-candidates.md) | `toolhead`, `n20`, `actuator`, `commissioning` |
| 2026-09-09 | `HW-20260909-001` | partial | [Verify guarded lift-home repeatability](../hardware/2026/2026-09-09-verify-guarded-lift-home-repeatability.md) | `toolhead`, `lift-home`, `t-01g`, `commissioning` |
| 2026-09-08 | `WSW-20260908-001` | implemented | [Calibrate the preview motion-time estimate](../windows-software/2026/2026-09-08-calibrate-preview-motion-estimate.md) | `preview`, `timing`, `m-06`, `calibration` |
| 2026-09-08 | `RPSW-20260908-002` | verified | [Fix integrated service-UART telemetry suppression](2026/2026-09-08-fix-integrated-service-uart-telemetry.md) | `toolhead`, `uart`, `telemetry`, `diagnostics` |
| 2026-09-08 | `RPSW-20260908-001` | implemented | [Add LIFT_HOME UART diagnostic sketch](2026/2026-09-08-add-lift-home-uart-diagnostic.md) | `toolhead`, `lift-home`, `uart`, `diagnostics`, `t-01g` |
| 2026-09-08 | `HW-20260908-004` | implemented | [Install LIFT_HOME switch input diagnostics](../hardware/2026/2026-09-08-install-lift-home-switch-input.md) | `toolhead`, `lift-home`, `t-01g`, `safety` |
| 2026-09-08 | `HW-20260908-003` | implemented | [Record current spring geometry](../hardware/2026/2026-09-08-record-current-spring-geometry.md) | `toolhead`, `spring`, `t-01a`, `safety` |
| 2026-09-08 | `HW-20260908-002` | verified | [Verify toolhead power-path gates](../hardware/2026/2026-09-08-verify-toolhead-power-path.md) | `toolhead`, `power`, `d36v50f6`, `drv8833`, `e-14` |
| 2026-09-07 | `HW-20260907-002` | verified | [Verify converter motion and guarded X/Y envelope](../hardware/2026/2026-09-07-verify-converter-motion-and-guarded-xy-envelope.md) | `m-03`, `m-06`, `m-07`, `soft-limits`, `g54`, `xya` |
| 2026-09-07 | `HW-20260907-001` | planned | [Require scale-force transfer calibration](../hardware/2026/2026-09-07-require-scale-force-transfer-calibration.md) | `force-calibration`, `hx711`, `grams-force`, `toolhead`, `testing` |
| 2026-09-06 | `RPSW-20260906-001` | implemented | [Add GP27 Normal-Status Guardrails](2026/2026-09-06-gp27-normal-status-guardrails.md) | `gp27`, `contact-ready`, `p100`, `safety` |
| 2026-09-06 | `HW-20260906-006` | verified | [Set temporary manual pen-corrected G54 XY reference](../hardware/2026/2026-09-06-set-temporary-manual-g54-xy-reference.md) | `g54`, `bed-center`, `tmag`, `pen-offset`, `commissioning` |
| 2026-09-06 | `HW-20260906-005` | verified | [Commission X/Y physical homing](../hardware/2026/2026-09-06-commission-xy-physical-homing.md) | `homing`, `limits`, `xy`, `m-07`, `commissioning` |
| 2026-09-06 | `HW-20260906-004` | verified | [Verify pen-free coordinated X/Y/A repeatability](../hardware/2026/2026-09-06-xya-coordinated-smoke-test.md) | `xya`, `coordinated-motion`, `m-06`, `repeatability`, `commissioning` |
| 2026-09-06 | `HW-20260906-003` | verified | [Configure the A axis without a finite travel limit](../hardware/2026/2026-09-06-a-axis-unlimited-travel-configuration.md) | `a-axis`, `rotary`, `soft-limits`, `configuration` |
| 2026-09-06 | `HW-20260906-002` | verified | [Verify X-axis rate and dimensional calibration](../hardware/2026/2026-09-06-x-axis-rate-and-dimensional-calibration.md) | `x-axis`, `rate`, `acceleration`, `dimensional-calibration`, `commissioning` |
| 2026-09-05 | `WSW-20260905-005` | implemented | [Consolidate current documentation ownership](../windows-software/2026/2026-09-05-consolidate-current-documentation.md) | `documentation`, `consolidation`, `source-of-truth`, `grblhal`, `toolhead` |
| 2026-09-05 | `WSW-20260905-004` | implemented | [Make converter programs self-contained for ioSender](../windows-software/2026/2026-09-05-self-contained-iosender-program-contract.md) | `iosender`, `grblhal`, `gcode`, `m3`, `m5`, `z-axis` |
| 2026-09-05 | `WSW-20260905-003` | implemented | [Record ioSender-to-converter compatibility review](../windows-software/2026/2026-09-05-iosender-converter-compatibility-review.md) | `iosender`, `grblhal`, `gcode`, `p100`, `integration-review` |
| 2026-09-05 | `WSW-20260905-002` | implemented | [Implement radius-aware A-axis feed for drawing](../windows-software/2026/2026-09-05-radius-aware-a-feed-requirement.md) | `theta`, `a-axis`, `tangential-speed`, `radius`, `feed-planning` |
| 2026-09-05 | `HW-20260905-006` | verified | [Verify Y-axis dimensional calibration](../hardware/2026/2026-09-05-m-03-y-axis-dimensional-calibration.md) | `y-axis`, `dimensional-calibration`, `steps-per-mm`, `commissioning` |
| 2026-09-05 | `HW-20260905-005` | verified | [Verify the Y-axis rate and acceleration baseline](../hardware/2026/2026-09-05-m-02-y-axis-rate-verification.md) | `y-axis`, `rate`, `acceleration`, `commissioning` |
| 2026-09-05 | `HW-20260905-004` | verified | [Verify the A-axis 12:1 bed ratio](../hardware/2026/2026-09-05-m-05-bed-ratio-verification.md) | `a-axis`, `bed-ratio`, `calibration`, `commissioning` |
| 2026-09-05 | `HW-20260905-003` | verified | [Correct A-axis calibration and characterize the F5000 ramp](../hardware/2026/2026-09-05-a-axis-rate-calibration-and-acceleration-check.md) | `a-axis`, `calibration`, `acceleration`, `tb6600`, `commissioning` |
| 2026-09-05 | `HW-20260905-002` | verified | [Verify installed TB6600 signal response](../hardware/2026/2026-09-05-tb6600-installed-signal-response.md) | `tb6600`, `step`, `direction`, `enable`, `e-03`, `commissioning` |
| 2026-09-05 | `HW-20260905-001` | verified | [RP23CNC USB source-selector bring-up](../hardware/2026/2026-09-05-rp23cnc-usb-source-selector-bringup.md) | `rp23cnc`, `usb`, `power-selector`, `tb6600` |
| 2026-09-04 | `WSW-20260904-001` | implemented | [Move pen/TMAG XY offset ownership to P100](../windows-software/2026/2026-09-04-remove-converter-tool-offset.md) | `coordinate-frames`, `tool-offset`, `p100`, `g54` |
| 2026-09-04 | `HW-20260904-007` | implemented | [Replace Toolhead Preload Spring](../hardware/2026/2026-09-04-replace-toolhead-preload-spring.md) | `toolhead`, `spring`, `preload`, `lift`, `testing` |
| 2026-09-04 | `HW-20260904-006` | implemented | [Make Pulse Response Tool-Specific During Preflight](../hardware/2026/2026-09-04-per-tool-pulse-response-preflight.md) | `toolhead`, `n20`, `force-control`, `interchangeable-tools`, `preflight` |
| 2026-09-03 | `RPSW-20260903-008` | implemented | [Add Opto-Isolation Presentation Slide](2026/2026-09-03-add-opto-isolation-presentation-slide.md) | `presentation`, `opto-isolation`, `wiring`, `p100` |
| 2026-09-03 | `HW-20260903-001` | implemented | [Record TB6600 signal and A-axis commissioning baseline](../hardware/2026/2026-09-03-record-tb6600-signal-and-a-axis-commissioning-baseline.md) | `tb6600`, `stepper`, `a-axis`, `calibration`, `homing` |
| 2026-09-02 | `RPSW-20260902-007` | implemented | [Full-Bleed Opening Slide Image](2026/2026-09-02-full-bleed-opening-slide-image.md) | `presentation`, `title-slide`, `toolhead` |
| 2026-09-02 | `RPSW-20260902-006` | implemented | [Refresh Summer Presentation Opening Render](2026/2026-09-02-refresh-summer-presentation-opening-render.md) | `presentation`, `toolhead`, `summer-progress` |
| 2026-09-02 | `RPSW-20260902-005` | implemented | [Expand P100 Presentation to Full Slide](2026/2026-09-02-expand-p100-presentation-to-full-slide.md) | `presentation`, `p100`, `interaction`, `layout` |
| 2026-09-02 | `RPSW-20260902-004` | implemented | [Align P100 Presentation Detail States](2026/2026-09-02-align-p100-presentation-detail-states.md) | `presentation`, `p100`, `interaction`, `correction` |
| 2026-09-02 | `RPSW-20260902-003` | implemented | [Add P100 Presentation Interaction](2026/2026-09-02-add-p100-presentation-interaction.md) | `presentation`, `p100`, `interaction`, `toolhead` |
| 2026-09-02 | `RPSW-20260902-002` | implemented | [Add Summer Progress Presentation](2026/2026-09-02-add-summer-progress-presentation.md) | `presentation`, `summer-progress`, `p100`, `toolhead`, `force-control` |
| 2026-09-02 | `RPSW-20260902-001` | implemented | [Add Current System Data Flow Chart](2026/2026-09-02-current-system-data-flow.md) | `data-flow`, `system-architecture`, `plotting`, `p100`, `toolhead`, `safety` |
| 2026-09-02 | `HW-20260902-001` | planned | [Plan Interchangeable-Tool Force Preflight](../hardware/2026/2026-09-02-plan-interchangeable-tool-force-preflight.md) | `toolhead`, `interchangeable-tools`, `load-cell`, `p100`, `pen-clear`, `testing` |
| 2026-09-01 | `HW-20260901-002` | planned | [Persist Toolhead Force Profile Separately from Boot Baseline](../hardware/2026/2026-09-01-persist-toolhead-force-profile.md) | `toolhead`, `load-cell`, `calibration`, `force-profile`, `startup-baseline`, `nonvolatile-storage` |
| 2026-09-01 | `HW-20260901-001` | planned | [Separate Normal Pen Clear from LIFT Home](../hardware/2026/2026-09-01-separate-pen-clear-from-lift-home.md) | `toolhead`, `m3`, `m5`, `pen-clear`, `lift-home`, `load-cell` |
| 2026-08-30 | `HW-20260830-005` | planned | [Plan Toolhead LIFT-Home Switch](../hardware/2026/2026-08-30-plan-toolhead-lift-home-switch.md) | `toolhead`, `lift-home`, `microswitch`, `gp2` |
| 2026-08-30 | `HW-20260830-001` | planned | [Plan Toolhead Motor/Preload Physical-Envelope Test](../hardware/2026/2026-08-30-toolhead-motor-preload-test-plan.md) | `toolhead`, `preload`, `spring`, `n20`, `force-control`, `test-plan` |
| 2026-08-28 | `WSW-20260828-001` | implemented | [Establish sequential agent execution policy](../windows-software/2026/2026-08-28-agent-execution-policy.md) | `agent-workflow`, `token-efficiency`, `quality`, `project-policy` |
| 2026-08-25 | `RPSW-20260825-001` | planned | [Plan Slow PI Toolhead Force Control](2026/2026-08-25-plan-slow-pi-toolhead-force-control.md) | `toolhead`, `load-cell`, `n20`, `force-control`, `pi` |
| 2026-08-23 | `HW-20260823-001` | implemented | [Partially terminate toolhead-control harness](../hardware/2026/2026-08-23-partially-terminate-toolhead-control-harness.md) | `toolhead`, `optocoupler`, `wiring`, `rp23cnc` |
| 2026-08-22 | `RPSW-20260822-003` | implemented | [Implement Dual-Core Magnetic Registration](2026/2026-08-22-dual-core-magnetic-registration.md) | `dual-core`, `magnetic-registration`, `centroid`, `probe` |
| 2026-08-22 | `RPSW-20260822-002` | implemented | [Correct RP2350 Toolhead Ownership](2026/2026-08-22-correct-rp2350-toolhead-ownership.md) | `toolhead`, `rp2350`, `tmag5273`, `documentation-correction` |
| 2026-08-22 | `RPSW-20260822-001` | planned | [Motorless PRB/G38 Feasibility Test](2026/2026-08-22-motorless-prb-g38-feasibility-test.md) | `probing`, `magnetic-calibration`, `motorless-test`, `g38` |
| 2026-08-22 | `HW-20260822-002` | implemented | [Route toolhead PC817 harness](../hardware/2026/2026-08-22-route-toolhead-pc817-harness.md) | `toolhead`, `optocoupler`, `drag-chain`, `wiring` |
| 2026-08-22 | `HW-20260822-001` | verified | [Verify X/Y limit live inputs](../hardware/2026/2026-08-22-verify-x-y-limit-live-inputs.md) | `limits`, `homing`, `safety`, `iosender` |
| 2026-08-19 | `HW-20260819-002` | implemented | [Correct TB6600 Axis Switch Settings](../hardware/2026/2026-08-19-correct-tb6600-axis-switch-settings.md) | `tb6600`, `dip-switch`, `microstepping`, `current-limit`, `x-axis`, `y-axis`, `a-axis` |
| 2026-08-15 | `HW-20260815-003` | implemented | [Set X/Y 20T baseline](../hardware/2026/2026-08-15-set-xy-20t-baseline.md) | `x-axis`, `y-axis`, `gt2`, `calibration` |
| 2026-08-15 | `HW-20260815-002` | implemented | [Select A-axis TB6600 baseline](../hardware/2026/2026-08-15-select-a-axis-tb6600-baseline.md) | `a-axis`, `tb6600`, `microstepping`, `calibration` |
| 2026-08-14 | `RPSW-20260814-006` | implemented | [Document ioSender in the system overview](2026/2026-08-14-document-iosender-in-system-overview.md) | `iosender`, `system-overview`, `gcode` |
| 2026-08-14 | `RPSW-20260814-004` | verified | [RP23U5XBB grblHAL baseline build prepared](2026/2026-08-14-rp23cnc-grblhal-baseline-build.md) | `rp23cnc`, `rp23u5xbb`, `grblhal`, `firmware-build`, `web-builder` |
| 2026-08-14 | `RPSW-20260814-003` | verified | [Add E-09 TMAG5273 Intended-Wiring Test](2026/2026-08-14-e09-tmag5273-verification-test.md) | `tmag5273`, `i2c`, `qwiic`, `toolhead` |
| 2026-08-14 | `RPSW-20260814-002` | verified | [Add E-08 HX711 Rate and Noise Test](2026/2026-08-14-e08-hx711-rate-noise-test.md) | `hx711`, `sample-rate`, `noise`, `toolhead` |
| 2026-08-14 | `HW-20260814-005` | planned | [Use the RP23CNC Halt input for the initial E-stop](../hardware/2026/2026-08-14-rp23cnc-halt-input-estop.md) | `estop`, `safety`, `rp23cnc` |
| 2026-08-14 | `HW-20260814-004` | planned | [Select X/Y Roller-Lever Limit Switches](../hardware/2026/2026-08-14-select-xy-roller-limit-switches.md) | `limit-switch`, `homing`, `safety`, `rp23cnc` |
| 2026-08-14 | `HW-20260814-003` | verified | [Correct TMAG5273 I2C SDA/SCL Mapping](../hardware/2026/2026-08-14-correct-tmag-i2c-sda-scl-mapping.md) | `tmag5273`, `i2c`, `qwiic`, `wiring-correction` |
| 2026-08-14 | `HW-20260814-002` | implemented | [Toolhead UART Service Calibration Fixture](../hardware/2026/2026-08-14-toolhead-uart-service-calibration.md) | `toolhead`, `uart`, `hx711`, `calibration` |
| 2026-08-14 | `HW-20260814-001` | implemented | [Require complete E-series test records](../hardware/2026/2026-08-14-e-series-test-record-requirement.md) | `verification`, `lab-notes`, `test-process` |
| 2026-08-11 | `HW-20260811-002` | implemented | [Moved HX711 to adjacent GP0/GP1 pins](../hardware/2026/2026-08-11-hx711-adjacent-jst-pins.md) | `rp2350`, `hx711`, `jst`, `pin-assignment` |
| 2026-08-11 | `HW-20260811-001` | superseded | [Reconciled E-stop and HD064RT topology (superseded)](../hardware/2026/2026-08-11-estop-hd064rt-topology.md) | `emergency-stop`, `power-distribution`, `hd064rt`, `rp23cnc` |
| 2026-08-10 | `HW-20260810-005` | implemented | [Direct-Header Toolhead Harness](../hardware/2026/2026-08-10-direct-header-toolhead-harness.md) | `jst`, `harness`, `rp2350`, `pc817` |
| 2026-08-10 | `HW-20260810-004` | implemented | [Record Recommended System Test Sequence](../hardware/2026/2026-08-10-recommended-system-test-sequence.md) | `test-plan`, `safety`, `sequencing` |
| 2026-08-10 | `HW-20260810-001` | verified | [Minimum-wire PC817 interface](../hardware/2026/2026-08-10-minimum-wire-pc817-interface.md) | `pc817`, `perfboard`, `isolation`, `kicad`, `gpio20` |
| 2026-08-06 | `HW-20260806-002` | implemented | [KiCad PC817C interface and active-low correction](../hardware/2026/2026-08-06-kicad-pc817-perfboard-schematic.md) | `kicad`, `optocoupler`, `perfboard`, `a-home` |
| 2026-08-06 | `HW-20260806-001` | superseded | [Compact PC817 interface module proposal](../hardware/2026/2026-08-06-compact-pc817-interface-module-proposal.md) | `optocoupler`, `pcb-layout`, `toolhead`, `a-home` |
| 2026-08-02 | `HW-20260802-001` | implemented | [Toolhead Local 5 V Regulator And 6 V Rail](../hardware/2026/2026-08-02-toolhead-local-5v-regulator.md) | `power`, `toolhead`, `regulator`, `drag-chain` |
| 2026-07-31 | `RPSW-20260731-001` | verified | [RP2350 Toolhead Prototype Firmware](2026/2026-07-31-rp2350-toolhead-prototype-firmware.md) | `toolhead`, `rp2350`, `arduino`, `drv8833`, `hx711`, `tmag5273` |
| 2026-07-31 | `HW-20260731-001` | implemented | [Toolhead Wiring Diagram](../hardware/2026/2026-07-31-toolhead-wiring-diagram.md) | `wiring`, `toolhead`, `rp2350`, `drv8833`, `hx711`, `tmag5273` |
| 2026-07-04 | `WSW-20260704-001` | implemented | [Project Management Overview HTML](../windows-software/2026/2026-07-04-project-management-overview-html.md) | `project-management`, `dashboard`, `documentation`, `navigation` |
| 2026-07-04 | `RPSW-20260704-003` | implemented | [Homing Data Flow Sheet](2026/2026-07-04-homing-data-flow-sheet.md) | `homing`, `data-flow`, `grblhal`, `tmag5273`, `toolhead` |
| 2026-07-04 | `RPSW-20260704-002` | implemented | [Pen-Up Calibration Workflow](2026/2026-07-04-pen-up-calibration-workflow.md) | `homing`, `calibration`, `toolhead`, `safety` |
| 2026-07-04 | `RPSW-20260704-001` | planned | [Magnetic Homing Calibration Plan](2026/2026-07-04-magnetic-homing-calibration-plan.md) | `homing`, `tmag5273`, `rp2040`, `magnetic-calibration`, `grblhal` |
| 2026-07-04 | `HW-20260704-003` | implemented | [Fixed TMAG5273 Height](../hardware/2026/2026-07-04-fixed-tmag5273-height.md) | `tmag5273`, `magnetic-calibration`, `sensor-mount`, `homing` |
| 2026-07-04 | `HW-20260704-002` | implemented | [RP23CNC Reference PDFs](../hardware/2026/2026-07-04-rp23cnc-reference-pdfs.md) | `rp23cnc`, `rp23u5xbb`, `references`, `manual` |
| 2026-07-04 | `HW-20260704-001` | implemented | [Electronics Layout Wiring HTML](../hardware/2026/2026-07-04-electronics-layout-wiring-html.md) | `wiring`, `layout`, `electronics`, `rp23cnc`, `tmag5273`, `toolhead` |
| 2026-06-09 | `RPSW-20260609-001` | planned | [RP23U5XBB Ethernet Bring-Up Plan](2026/2026-06-09-rp23u5xbb-ethernet-bring-up-plan.md) | `grblhal`, `ethernet`, `w5500`, `firmware-build` |
| 2026-06-07 | `WSW-20260607-004` | verified | [Single-File Engineering Topic Index](../windows-software/2026/2026-06-07-single-file-engineering-topic-index.md) | `engineering-log`, `topic-index`, `navigation`, `single-source` |
| 2026-06-07 | `WSW-20260607-003` | verified | [Documentation Navigation and Index Automation](../windows-software/2026/2026-06-07-documentation-navigation-and-index-automation.md) | `documentation`, `navigation`, `automation`, `maintainability` |
| 2026-06-07 | `WSW-20260607-002` | verified | [Continuous Maintainability Policy](../windows-software/2026/2026-06-07-continuous-maintainability-policy.md) | `maintainability`, `technical-debt`, `documentation`, `project-policy` |
<!-- END GENERATED CHANGES -->

See the [combined change index](../INDEX.md).

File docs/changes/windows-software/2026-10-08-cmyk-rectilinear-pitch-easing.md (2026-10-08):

---
id: WSW-20261008-017
date: 2026-10-08
category: windows-software
affected_categories:
  - windows-software
status: implemented
components:
  - software/converter_core/cmyk.py
  - software/tests/test_cmyk_tab.py
  - software/README.md
tags:
  - cmyk
  - screening
  - rectilinear
  - banding
related:
  - WSW-20261008-016
---

# Rectilinear pitch follows the inked tone and eases between rows

## Summary

The rectilinear screen advanced its row pitch from the *whole row's* average
tone, blank paper included, and it took that step in one go. A row crossing
both the subject and the background therefore jumped the spacing between
neighbouring rows, which is what the owner saw as striations in smooth areas
like the forehead. The advance now uses the mean tone of the samples the row
actually inks (values at or above the ink floor) and eases that tone over
successive rows, so the pitch still follows the picture but no longer steps.
On an edge fixture the largest gap-to-gap jump falls to 1.10x.

## Reason

Owner: "why are there striations". Measured on the owner's preview: rows sit
one pen width apart (0.11 mm x 280 % = 0.31 mm with a 0.30 mm pen), so tone is
carried by row spacing, and the spacing stepped wherever the row average
changed.

## Implementation

- `software/converter_core/cmyk.py`: `_line_runs` keeps an `eased_tone`
  running value; inked samples only, half-way step per row.

## Verification

- `python -m unittest discover -s software\tests -p "test_*.py"`: 403 tests
  pass, 1 skipped (the pre-existing headless shader compile).
- New test: a paper-to-0.35-tone edge gives a row-pitch sequence whose
  largest consecutive jump is under 1.25x.

## Struggles and rejected approaches

- Making the pitch strictly local (per run) was rejected: the rows are
  straight lines, so a per-run pitch would either bend them or seam the page
  into strips. Easing the row pitch removes the visible step without new
  geometry.

## Risks and follow-up

- The screen still quantises tone into discrete rows, so some texture remains;
  crosshatch at a fixed pitch is the alternative when a uniform screen
  matters more than the joined-row pen economy.

## Files

- `software/converter_core/cmyk.py`: eased row pitch in `_line_runs`.
- `software/tests/test_cmyk_tab.py`: edge banding test.
- `software/README.md`: rectilinear description.

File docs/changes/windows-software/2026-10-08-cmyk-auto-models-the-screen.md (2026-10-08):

---
id: WSW-20261008-016
date: 2026-10-08
category: windows-software
affected_categories:
  - windows-software
status: implemented
components:
  - software/converter_core/cmyk.py
  - software/generator_tabs/cmyk_tab.py
  - software/tests/test_cmyk_tab.py
  - software/README.md
tags:
  - cmyk
  - automation
  - screening
  - density
related:
  - WSW-20261008-014
  - WSW-20261008-015
---

# Auto renders the screen before it picks the tone

## Summary

Auto assumed the tone it asked for was the ink the plot lays down. The
rectilinear screen does not work that way: rows sit one pen width apart and
open up by up to 7x in light tones, so a light tone only inks about a fifth
of its area. The tab now passes Pen width and the effective pitch
(`Dot pitch x Artwork scale`) into `auto_photo_settings`, which converts each
candidate's tone into row coverage (`pen / row pitch`, cut off below the ink
floor), multiplies the four inks and scores the rendered luminance. The
screen-aware search also covers the darker half of the controls (brightness
60-180 %, gamma 0.6-1.6) because "more ink" is the only way to reach the
photo's tone on a sparse screen.

## Reason

Owner: "i ran auto again", with a pale preview at C 120 / B 100 / gamma 1.0 -
Auto's tone term had aimed the *tone* at the photo, but the screen rendered
that tone at roughly half the coverage, so the plot came out washed out.

## Implementation

- `software/converter_core/cmyk.py`: optional `pen_width_mm` and
  `effective_pitch_mm`; the screen branch renders tones through the
  rectilinear stretch, the ink floor, the display inks and the tab's tone
  grid. Saturation and GCR are computed before the search so the render uses
  them.
- `software/generator_tabs/cmyk_tab.py`: the Auto button passes the current
  Pen width and effective pitch.

## Verification

- `python -m unittest discover -s software\tests -p "test_*.py"`: 402 tests
  pass, 1 skipped (the pre-existing headless shader compile).
- Owner's portrait at 0.30 mm pen / 0.31 mm rows: C 270 / B 100 / gamma 0.60
  (was C 120 / B 100 / 1.0). Wisteria: C 240 / B 60 / gamma 1.0.
- New test: a sparse screen (0.31 mm rows) returns a darker chain than the
  tone-only model, and a screen finer than the pen (0.10 mm) returns a
  lighter one.

## Struggles and rejected approaches

- Keeping the tone-only search and just adding the darker grid points was
  rejected: without the screen model the search already matched the photo's
  tone and would not have moved.
- A full colour fit was again measured and rejected - the ink model adds
  contrast, so a least-|print - photo| fit collapses to the lowest-ink
  corner.

## Risks and follow-up

- Plots will ask for much more ink on sparse screens: expect longer runs and
  more pooling. Judge the first one on paper before batch printing.
- The screen model uses the display ink colours, not a loaded calibration
  profile.

## Files

- `software/converter_core/cmyk.py`: screen model in the Auto search.
- `software/generator_tabs/cmyk_tab.py`: tab feeds pen width and effective
  pitch.
- `software/tests/test_cmyk_tab.py`: sparse-vs-fine screen test, tab Auto
  expectation.
- `software/README.md`: Auto description.

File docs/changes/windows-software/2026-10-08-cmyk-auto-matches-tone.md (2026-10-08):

---
id: WSW-20261008-014
date: 2026-10-08
category: windows-software
affected_categories:
  - windows-software
status: implemented
components:
  - software/converter_core/cmyk.py
  - software/tests/test_cmyk_tab.py
  - software/README.md
tags:
  - cmyk
  - automation
  - tone
  - portraits
related:
  - WSW-20261008-010
  - WSW-20261008-011
---

# Auto matches the printed tone to the photo

## Summary

`auto_photo_settings` scored the tone chain on detail energy alone, so on a
bright low-contrast portrait it chose brightness 140 / contrast 180 and the
print came out a stop lighter than the photo (mean paper luminance 0.511
against 0.434) - which is exactly where skin washes out and reads pink. The
score now subtracts the printed tone error as well: the search aims the
print's mean tone at the photo's, clamped to the 0.30-0.75 window a plot can
hold (below it the sheet is a muddy ink stack, above it is mostly paper).
Dark photos therefore keep the deliberate lift that keeps their structure
visible.

## Reason

Owner: "auto just looks so bad on skin tones", with the Auto result
(S 125 / C 180 / B 140 / GCR 90 / gamma 1.0) on `momandbennett.jpg`.
Measured through the real chain plus the multiply ink model: the chosen
settings print at 0.511 mean paper luminance against the photo's 0.434, and
the predicted skin is lighter and pinker than the photo's.

## Implementation

- `software/converter_core/cmyk.py`: `photo_tone = clamp(stretched.mean(),
  0.30, 0.75)`; the search score is
  `_detail_score(printed) - abs(printed.mean() - photo_tone)`.
- On the owner's portrait Auto now returns brightness 100 / contrast 120
  (printed 0.432 against 0.434); the wisteria photo is unchanged
  (printed 0.517 against 0.513).

## Verification

- `python -m unittest discover -s software\tests -p "test_*.py"`: 400 tests
  pass, 1 skipped (the pre-existing headless shader compile).
- New regression test: on a bright low-contrast field, where the detail-only
  search picked brightness 120 and printed 0.044 lighter than the photo, the
  chosen settings now come within 0.03 of the photo's tone.
- The dark/bright test keeps its lift requirement (brightness 180); its
  gamma expectation moves 1.5 -> 1.4 because the window clamp trades a
  little of the lift away.

## Struggles and rejected approaches

- A full colour fit (choose the settings that minimise mean
  `|print - photo|`) was measured and rejected: the ink model adds contrast,
  so the minimum is the same lowest-ink corner (brightness 100, contrast
  120, saturation 100) for every image, which flattens the print.
- Matching the printed mean with no clamp (weight 1.0 everywhere) dropped a
  dark test photo's detail score from 0.126 to 0.020, which is why the
  printable window exists.

## Risks and follow-up

- Auto still fits the built-in display inks; the measured calibration profile
  remains the exact-match step.
- Skin keeps the muted-image saturation boost (up to 145 %). If skin reads
  too pink, drop Saturation 10-15 points after Auto.

## Files

- `software/converter_core/cmyk.py`: tone term in the Auto search.
- `software/tests/test_cmyk_tab.py`: tone-match regression test; dark/bright
  expectation.
- `software/README.md`: Auto description.

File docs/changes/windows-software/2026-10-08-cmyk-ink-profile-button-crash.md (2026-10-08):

---
id: WSW-20261008-013
date: 2026-10-08
category: windows-software
affected_categories:
  - windows-software
status: implemented
components:
  - software/qt_svg_to_gcode.pyw
  - software/tests/test_generator_tabs.py
tags:
  - cmyk
  - preview
  - crash
  - ink-profile
related:
  - WSW-20261007-007
---

# Ink profile button no longer kills the app

## Summary

Pressing **Ink profile...** took the application down instead of opening a
file picker. The button was wired straight to `load_ink_profile(path=None)`,
and Qt hands a clicked slot its `checked` flag - so `path` arrived as
`False`, the dialog was skipped, and the loader read file descriptor 0
instead of a profile. The button now uses a dedicated `choose_ink_profile`
slot that ignores the flag, and `load_ink_profile` refuses any argument that
is not a path.

## Reason

Owner report: "the ink profile... button crashes the app". The last line of
`software/qt_debug.log` is Python's warning for exactly that call:
`qt_svg_to_gcode.pyw:4014: RuntimeWarning: bool is used as a file descriptor`
followed by `with open(path, "r", encoding="utf-8") as handle:`.

## Implementation

- `software/qt_svg_to_gcode.pyw`: the button connects to
  `choose_ink_profile(_checked=False)`, which opens the picker and calls
  `load_ink_profile(path)`. The loader now raises `TypeError` for non-path
  arguments, so a future signal mis-wiring is visible instead of fatal.

## Verification

- `open(False, "r", encoding="utf-8")` was checked on this Python 3.13.13
  under both `python` and `pythonw`: it opens file descriptor 0 with the
  RuntimeWarning instead of raising, so the press never reached a profile
  file - the app log ends with that warning at the moment of the press. The
  exact way the Qt process then went down could not be reproduced outside
  the app.
- `python -m unittest discover -s software\tests -p "test_*.py"`: 399 tests
  pass, 1 skipped (the pre-existing headless shader compile). The new test
  clicks the real button with a stubbed `QFileDialog` and asserts the
  measured colours reach `gl_preview.sim_ink_colors`, and that
  `load_ink_profile(False)` raises instead of opening fd 0.

## Struggles and rejected approaches

- The profile JSON path was inspected first; the trailing RuntimeWarning in
  the app log pointed at the slot signature instead. Keeping the dialog
  inside `load_ink_profile` and sniffing a bool argument was rejected: the
  signal flag should never be able to look like a path.

## Risks and follow-up

- The other preview buttons (`Fit inside`, `Fill bed`, `Play`, `Pause`,
  `Preview`, `Cancel`) take no positional arguments, so they cannot hit the
  same trap.

## Files

- `software/qt_svg_to_gcode.pyw`: split the picker out of the loader; guard
  the loader.
- `software/tests/test_generator_tabs.py`: button-click regression test.

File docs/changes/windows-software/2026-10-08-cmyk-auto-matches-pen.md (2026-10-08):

---
id: WSW-20261008-012
date: 2026-10-08
category: windows-software
affected_categories:
  - windows-software
status: implemented
components:
  - software/generator_tabs/cmyk_tab.py
  - software/tests/test_cmyk_tab.py
  - software/README.md
tags:
  - cmyk
  - screening
  - automation
  - pitch
related:
  - WSW-20261008-010
  - WSW-20261008-009
---

# Auto (photo) also matches the pen pitch

## Summary

Pressing **Auto (photo)** now also sets Dot pitch to one pen width at the
current artwork scale - exactly what the **Match pen** button does. Auto
previously reported the effective pitch (`Dot pitch x Artwork scale` versus
pen width) as text advice and left the control alone, so a photo could be
auto-fitted and still screened at a density the pen cannot hold.

## Reason

Owner: "is dot pitch being adjusted during the auto button press?" - it was
not. The advice line could tell the operator the balance was off but did
nothing about it, and the effective pitch only reads correctly when it is
tied to the same artwork scale the Auto result is judged at.

## Implementation

- `software/generator_tabs/cmyk_tab.py`: `pen_pitch_mm()` returns
  `clamp(pen width / artwork scale, 0.1, 8.0)`; `match_pen_pitch()` uses it,
  and `apply_auto_settings` sets Dot pitch to it before reporting. The Auto
  status message states the pitch it chose (one pen width at the current
  scale) instead of the previous effective-pitch advisory.

## Verification

- `python -m unittest discover -s software\tests -p "test_*.py"`: 398 tests
  pass, 1 skipped (the pre-existing headless shader compile).
- `test_auto_button_applies_photo_settings` presses Auto at 150 % artwork
  scale with the 0.30 mm pen and asserts Dot pitch lands on 0.20 mm and the
  status message names it.
- `python tools\docs_index.py --write` and `--check` pass.

## Struggles and rejected approaches

- Keeping the trend advisory text alongside the auto-set pitch was rejected:
  after Auto the effective pitch is one pen width by construction, so the
  advisory would always print the same "good balance" sentence.

## Risks and follow-up

- Auto now overwrites a manually chosen Dot pitch. Operators who want a
  deliberately coarser or denser screen should set Dot pitch after Auto, the
  same way Auto already overwrites the tone controls.

## Files

- `software/generator_tabs/cmyk_tab.py`: shared pen-pitch helper; Auto sets
  the pitch.
- `software/tests/test_cmyk_tab.py`: Auto pitch assertion.
- `software/README.md`: Auto description updated.

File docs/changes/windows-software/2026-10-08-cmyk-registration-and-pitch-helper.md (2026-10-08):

---
id: WSW-20261008-009
date: 2026-10-08
category: windows-software
affected_categories:
  - windows-software
status: implemented
components:
  - software/generator_tabs/cmyk_tab.py
  - software/tests/test_cmyk_tab.py
  - software/README.md
tags:
  - cmyk
  - registration
  - workflow
  - user-interface
related:
  - WSW-20261008-008
  - WSW-20261008-002
---

# Add registration crosses and a pen-width pitch helper

## Summary

Two art-mode workflow aids:

1. **Registration corner crosses** (Page group, default off): every ink
   layer draws the same four small crosses in the page margin (inset =
   half the margin, clamped; arms up to 2.5 mm), so a four-pass plot can be
   checked for alignment while it runs. The crosses are appended after
   artwork scaling, so they stay at fixed page positions.
2. **Match pen** button beside Dot pitch: sets the pitch to
   `pen width / artwork scale` (clamped 0.1-8 mm), putting full-tone rows
   about one pen width apart - the effective-pitch rule made one click.

## Reason

Ranked improvements 3 and 4 from
`docs/research/2026-10-08-cmyk-vs-open-source.md`: pass misalignment is the
community's top failure mode and no open tool draws registration aids into
the job; DrawingBotV3's CMYK notes recommend "Rescale to Pen Width" while
our pitch/scale/pen-width relationship lived only in tooltips.

## Implementation

- `software/generator_tabs/cmyk_tab.py`: `registration_marks` checkbox and
  `_registration_crosses`; `match_pen_pitch`; the checkbox joins the layer
  cache key.
- `software/README.md`: control list.

## Verification

- `python -m unittest discover -s software\tests -p "test_*.py"` passes 396
  tests (1 skipped: the pre-existing headless shader compile). New tests:
  the eight cross polylines are identical at the end of every ink
  layer and absent when the checkbox is off; Match pen yields 0.15 mm at
  200 % scale with a 0.30 mm pen.
- `python tools\docs_index.py --write` and `--check` pass.

## Struggles and rejected approaches

- Placing crosses inside the artwork area was rejected: margin placement
  keeps them off the image and visible while the plot runs.
- Scaling the crosses with the artwork was rejected: alignment references
  must stay at fixed page positions.

## Risks and follow-up

- The crosses verify alignment; they do not correct it (registration stays
  mechanical). Margin under ~2 mm clamps the crosses to a 0.5 mm arm.

## Files

- `software/generator_tabs/cmyk_tab.py`: checkbox, crosses, Match pen.
- `software/tests/test_cmyk_tab.py`: coverage.
- `software/README.md`: documentation.

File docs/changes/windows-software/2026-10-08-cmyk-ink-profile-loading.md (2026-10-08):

---
id: WSW-20261008-008
date: 2026-10-08
category: windows-software
affected_categories:
  - windows-software
status: implemented
components:
  - software/qt_svg_to_gcode.pyw
  - software/tests/test_generator_tabs.py
  - software/README.md
tags:
  - cmyk
  - calibration
  - ink-simulation
related:
  - WSW-20261008-007
  - WSW-20261007-022
  - WSW-20261007-014
---

# Load measured ink profiles into the simulation

## Summary

The preview panel gains an **Ink profile...** button. It loads the
`*-profile.json` that `tools/cmyk_calibrate.py` writes from a scanned
calibration sheet, and the Ink simulation then multiplies the pens'
measured transmittances instead of the display ink colours - the last step
of the calibration loop this repository already built. The loaded values
are logged, and the Ink simulation tooltip names the active profile. The
pale/drawn progress view keeps the display colours by design.

## Reason

Ranked improvement 1 from
`docs/research/2026-10-08-cmyk-vs-open-source.md`: every reference tool
concedes its preview is approximate (DrawingBotV3: "may differ from the
final plot; experimentation may be needed"), while our sheet plus analyzer
can measure the real inks - but nothing consumed the profile.

## Implementation

- `software/qt_svg_to_gcode.pyw`: `rgb_floats` and an `ink_colors` override
  in `ink_vertex_colors`; `GLPreview.set_sim_ink_colors` (clamped channel ->
  (r, g, b) map) feeding the solid multiply buffer;
  `MainWindow.load_ink_profile(path=None)` validates
  `kind == "cmyk-ink-profile"`, applies the inks, and reports them in the
  log. The **Ink profile...** button sits beside the Ink simulation
  checkbox.
- `software/README.md`: preview-panel note.

## Verification

- `python -m unittest discover -s software\tests -p "test_*.py"` passes 394
  tests (1 skipped: the pre-existing headless shader compile). New tests:
  measured colours override the display colours in `ink_vertex_colors`, and
  loading a profile JSON (real temp file) drives the GL solid buffer to the
  measured values.
- `python tools\docs_index.py --write` and `--check` pass.

## Struggles and rejected approaches

- Auto-discovering a profile beside the artwork was rejected: the scan tool
  names profiles after the scan file, so guessing would surprise more often
  than help. Loading is explicit.
- Recolouring the pale/drawn progress view with measured inks was rejected:
  that view identifies layer identity; the measured colours belong to the
  finished-print simulation only.

## Risks and follow-up

- The profile applies to the session until another is loaded; persistence
  per pen set is a follow-up. Exposure of measured values as editable
  sliders (DrawingBotV3-style per-pen multipliers) remains ranked item 6.

## Files

- `software/qt_svg_to_gcode.pyw`: override plumbing, loader, button.
- `software/tests/test_generator_tabs.py`: override and loader tests.
- `software/README.md`: documentation.

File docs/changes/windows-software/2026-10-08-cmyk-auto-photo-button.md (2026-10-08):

---
id: WSW-20261008-006
date: 2026-10-08
category: windows-software
affected_categories:
  - windows-software
status: implemented
components:
  - software/converter_core/cmyk.py
  - software/generator_tabs/cmyk_tab.py
  - software/tests/test_cmyk_tab.py
  - software/README.md
tags:
  - cmyk
  - user-interface
  - defaults
  - automation
related:
  - WSW-20261008-005
  - WSW-20261008-001
---

# Add an Auto (photo) button to the CMYK image options

## Summary

Image options gains an **Auto (photo)** button. It analyzes the loaded
artwork at a small resolution and fits the image-side controls so the ink
simulation starts close to the photo: auto levels on, brightness 100-180 %
(from the median luminance, so it only ever lifts dark images), contrast
120-285 % (from the inter-quartile tonal spread - flatter images get more),
saturation 100-140 % and GCR 70-95 % (from the mean chroma, so vivid photos
keep more colour), and a starting gamma 1.0-1.6 (from the median again,
left as the print-lightness dial to tweak). The status line reports the
values it chose, and every control stays manually editable.

## Reason

Owner: "is there a way we can add an 'auto' button to set it up as close to
a good representation of the photo as possible? im just having a hard time
between photos and it would be easier if all i had to manipulate after
'auto' was gamma." Nothing is removed; Auto is a starting point.

## Implementation

- `software/converter_core/cmyk.py`: `auto_photo_settings(image_path)` -
  downscale to 256 px, luminance percentiles (p25/p50/p75), mean chroma,
  and the clamped formulas above.
- `software/generator_tabs/cmyk_tab.py`: the Auto button at the top of
  Image options; `apply_auto_settings` sets the six controls and reports
  the chosen values in the status line.
- `software/README.md`: control-list note.

## Verification

- `python -m unittest discover -s software\tests -p "test_*.py"` passes 392
  tests (1 skipped: the pre-existing headless shader compile). New tests: a
  dark synthetic image gets gamma >= 1.3 and brightness >= 140 while a
  bright one stays at gamma 1.0 / brightness 100; clicking the button
  applies exactly the analyzer's values and writes the status line.
- `python tools\docs_index.py --write` and `--check` pass.

## Struggles and rejected approaches

- Predicting gamma exactly was rejected: gamma is the owner's single
  manual dial, so Auto only gives it a sensible start.
- Setting the Screen or Page controls was rejected: style, pitch, scale,
  and resolution stay workflow choices.

## Risks and follow-up

- The heuristics are deliberately conservative (brightness never darkens,
  saturation never lowers); unusual images may still want manual nudges.

## Files

- `software/converter_core/cmyk.py`: `auto_photo_settings`.
- `software/generator_tabs/cmyk_tab.py`: Auto button and handler.
- `software/tests/test_cmyk_tab.py`: analyzer and button coverage.
- `software/README.md`: documentation.

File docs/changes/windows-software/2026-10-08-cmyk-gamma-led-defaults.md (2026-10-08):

---
id: WSW-20261008-005
date: 2026-10-08
category: windows-software
affected_categories:
  - windows-software
status: implemented
components:
  - software/generator_tabs/cmyk_tab.py
  - software/tests/test_cmyk_tab.py
  - software/README.md
tags:
  - cmyk
  - defaults
  - gamma
  - tone
related:
  - WSW-20261008-004
  - WSW-20261008-003
---

# Set the CMYK defaults to the owner's gamma-led tuning

## Summary

The CMYK tab now ships the values the owner tuned to fix the dark,
muddy night-photo plot: **contrast 285 %** (inside the new 300 % soft-curve
range), **brightness 170 %**, **ink gamma 1.40**, **black (GCR) 95 %**,
weights **100/100/100/100 %**. Saturation 115 %, rectilinear fill at
0.10 mm pitch, artwork scale 280 %, resolution 10000 px, auto levels on,
hatch levels 8, and 40000 marks/ink are unchanged.

Ink gamma was the biggest lever: values above 1.0 raise each channel's tone
to a power (`tone ** gamma`), so 1.4 lays roughly a third less ink in the
mid tones - exactly what counters the four-ink overprint's natural
darkening. Brightness 170 lifts the image's shadows, and contrast 285
restores punch through the soft S-curve.

## Reason

Owner: "these changes improved things quite a bit especially gamma," with
the settings panel showing the values above and a clearly recognizable
portrait in the ink simulation.

## Implementation

- `software/generator_tabs/cmyk_tab.py`: contrast 200 -> 285, brightness
  130 -> 170, ink gamma 1.0 -> 1.40, GCR 65 -> 95, K weight 105 -> 100.
- `software/README.md`: shipped-defaults sentence and recommended row.

## Verification

- `python -m unittest discover -s software\tests -p "test_*.py"` passes 390
  tests (1 skipped: the pre-existing headless shader compile); the
  shipped-defaults test now asserts contrast 285, brightness 170, gamma
  1.40, GCR 95, and K weight 100.
- `python tools\docs_index.py --write` and `--check` pass.

## Struggles and rejected approaches

- Encoding the lift in brightness alone was rejected by the owner's own
  tuning: gamma changes ink coverage itself, so it lightens the print
  without washing out the image's structure.

## Risks and follow-up

- Gamma 1.40 is tuned for a dark scene; a well-exposed photo may want
  1.0-1.2. The measured calibration profile remains the final colour step.

## Files

- `software/generator_tabs/cmyk_tab.py`: the tuned defaults.
- `software/tests/test_cmyk_tab.py`: shipped-defaults assertions.
- `software/README.md`: current-state defaults.

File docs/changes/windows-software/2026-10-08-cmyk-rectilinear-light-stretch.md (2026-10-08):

---
id: WSW-20261008-002
date: 2026-10-08
category: windows-software
affected_categories:
  - windows-software
status: implemented
components:
  - software/converter_core/cmyk.py
  - software/tests/test_cmyk_tab.py
  - software/README.md
tags:
  - cmyk
  - rectilinear
  - tone
  - screening
related:
  - WSW-20261008-001
  - WSW-20261007-020
---

# Open rectilinear light tones instead of hatching them

## Summary

The rectilinear fill was structurally dark: its adaptive pitch capped at 3x
the base spacing, so with the shipped 0.10 mm pitch at 280 % artwork scale
the *lightest* possible coverage for one ink was ~36 % (a 0.3 mm pen over a
0.84 mm row gap). Every inked area therefore laid down at least a
third-coverage of all four films, and the multiply overprint crushed mid
tones and shadows to black. Rectilinear now opens the row pitch up to 7x in
the lightest tones (`light_stretch = 6`; the plain line screen keeps 3x).
Per-ink coverage now spans roughly 15 %-100 % at the shipped density instead
of 36 %-100 %, so highlights stay paper, mid tones keep roughly half their
former ink, and full tones still fuse solid.

## Reason

Owner: the previous result "made it look like this" - a night photo whose
simulation was almost entirely black with a few light streaks. The cause was
structural (coverage floor), not only the image options.

## Implementation

- `software/converter_core/cmyk.py`: `_line_runs` gains `light_stretch`
  (default 2.0, the historic behaviour); the rectilinear dispatch passes
  6.0, so its pitch factor is `1 + 6*(1 - tone)`.
- `software/README.md`: the shipped-defaults sentence notes the 7x
  light-tone stretch.

## Verification

- `python -m unittest discover -s software\tests -p "test_*.py"` passes 388
  tests (1 skipped: the pre-existing headless shader compile). New test: a
  20 % tone field produces fewer than 70 % of the line screen's rows; the
  chain, blank-band, sheet-ladder, and page-bounds tests still pass.
- `python tools\docs_index.py --write` and `--check` pass.

## Struggles and rejected approaches

- Raising the artwork scale or lowering the pitch was rejected: it keeps the
  36 % coverage floor and only trades which tones block up.
- Changing the shared line screen was rejected: the wide stretch is a
  rectilinear-fill choice, and the plain line screen keeps its established
  look.

## Risks and follow-up

- Light areas are now sparse parallel strokes; chains fragment more where
  the pitch opens, so M3 savings are largest in the mid and dark tones.
- The measured calibration profile is still the final step for matching the
  pens' hue and saturation.

## Files

- `software/converter_core/cmyk.py`: `light_stretch`, rectilinear value.
- `software/tests/test_cmyk_tab.py`: light-tone spacing regression test.
- `software/README.md`: current-state notes.

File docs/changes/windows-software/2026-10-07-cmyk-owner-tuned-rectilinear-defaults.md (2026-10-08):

---
id: WSW-20261007-025
date: 2026-10-07
category: windows-software
affected_categories:
  - windows-software
status: implemented
components:
  - software/generator_tabs/cmyk_tab.py
  - software/tests/test_cmyk_tab.py
  - software/tests/test_generator_tabs.py
  - software/README.md
tags:
  - cmyk
  - defaults
  - rectilinear
related:
  - WSW-20261007-024
  - WSW-20261007-023
---

# Set the CMYK defaults to the owner's tuned rectilinear set

## Summary

The CMYK tab now opens with the exact settings the owner tuned and
reported as great for the rectilinear fill: auto levels on, **saturation
130 %**, **contrast 200 %**, ink gamma 1.0, **black (GCR) 99 %**,
**resolution 10000 px**, weights **C 120 / M 120 / Y 120 / K 150 %**,
style **Rectilinear fill (joined rows)**, **dot pitch 0.10 mm**, dot size
100 %, solid dots off, hatch levels 8, overdraw 1, pen width 0.30 mm, max
marks 40000, seed 7, page 200 x 200 mm, margin 6 mm, **artwork scale
280 %**.

The two screenshots disagreed on one value: the first showed dot pitch
0.20 mm and the second 0.10 mm. The later state (0.10 mm) is used; it is a
single field to change if the other was meant.

## Reason

Owner: "these were all great settings, set these as defaults for
rectilinear."

## Implementation

- `software/generator_tabs/cmyk_tab.py`: the defaults above (saturation
  100 -> 130, contrast 100 -> 200, GCR 75 -> 99, resolution 6000 -> 10000,
  weights 100 -> 120/120/120/150, pitch 0.20 -> 0.10, hatch levels 5 -> 8,
  artwork scale 100 -> 280; style stays rectilinear).
- `software/tests/test_generator_tabs.py`: the every-tool artwork-scale
  convention test now expects 280 % for CMYK (it is the one tool whose
  tuned default is not 1:1) and 100 % for every other tool.
- `software/README.md`: shipped-defaults sentence and recommended-settings
  row.

## Verification

- `python -m unittest discover -s software\tests -p "test_*.py"` passes 386
  tests (1 skipped: the pre-existing headless shader compile). The
  shipped-defaults test asserts every value above, and the artwork-scale
  convention test covers the CMYK exception.
- `python tools\docs_index.py --write` and `--check` pass.

## Struggles and rejected approaches

- Averaging the two screenshots' pitches was rejected: both are the owner's
  real states, and 0.10 mm (later) is the denser choice they were moving
  toward.

## Risks and follow-up

- This is a very heavy ink load: 0.10 mm pitch with 280 % scale puts mid
  tones near 0.56 mm effective spacing at 150 % black weight. Expect
  multi-hour per-pen plots and check paper wetness on large fills.
- Artwork scale 280 % enlarges every new artwork about the page centre;
  it is a per-job choice for users who want the photo to fill the bed.

## Files

- `software/generator_tabs/cmyk_tab.py`: the tuned defaults.
- `software/tests/test_cmyk_tab.py`, `software/tests/test_generator_tabs.py`:
  default assertions and the scale convention exception.
- `software/README.md`: current-state defaults.

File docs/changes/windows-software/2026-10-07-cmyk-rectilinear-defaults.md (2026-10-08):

---
id: WSW-20261007-024
date: 2026-10-07
category: windows-software
affected_categories:
  - windows-software
status: implemented
components:
  - software/generator_tabs/cmyk_tab.py
  - software/tests/test_cmyk_tab.py
  - software/README.md
tags:
  - cmyk
  - defaults
  - rectilinear
related:
  - WSW-20261007-020
  - WSW-20261007-022
  - WSW-20261007-023
---

# Tune the CMYK defaults for the rectilinear fill

## Summary

The CMYK tab now opens with the settings that give the rectilinear fill its
best result: **Rectilinear fill (joined rows)** style, **Dot pitch
0.20 mm**, **Black (GCR) 75 %**, artwork scale 100 %, auto levels on,
pen 0.30 mm, overdraw 1, 40000 marks/ink, 6000 px resolution, weights
100 %.

Why those values: the effective row spacing is pitch x artwork scale x the
tone-adaptive factor (1-3x), and mid tones - the bulk of a photo - sit at
2x the set pitch. At 0.20 mm the mid tones land near 0.4 mm, about one pen
width, so adjacent rows (and the four inks) genuinely overlap and the
multiply simulation shows mixed colours; dark tones fuse solid, light tones
stay sparse by design. At GCR 75 % no CMY channel is forced to zero, so
cyan no longer collapses into patches on warm content the way 100 % GCR
does.

## Reason

Owner: "change the settings to provide the best result for rectilinear,"
after the preview inspection showed 200 % artwork scale had doubled the
effective pitch and GCR 100 % had flattened the colour mix.
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

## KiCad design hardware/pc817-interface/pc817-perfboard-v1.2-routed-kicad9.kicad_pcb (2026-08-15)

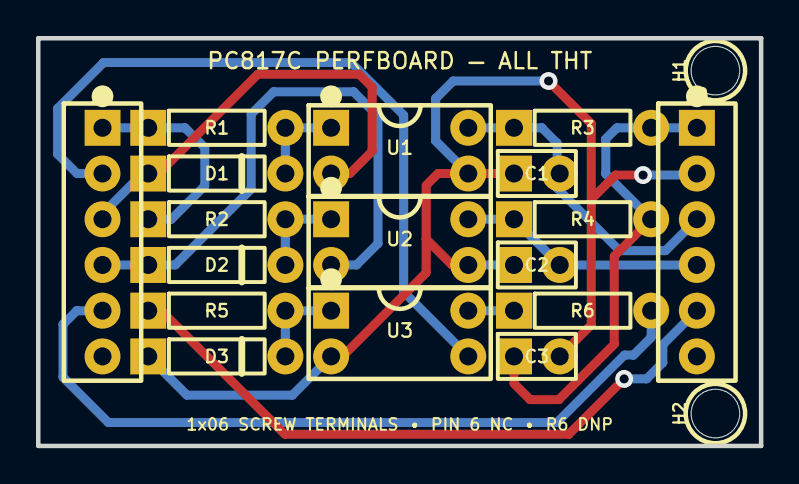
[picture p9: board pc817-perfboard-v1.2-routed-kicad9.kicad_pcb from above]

Board: 2 copper layers, 40.2 x 22.6 mm, 19 parts (0 on the bottom side), 14 nets.

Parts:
C1, C2: 47nF; Perfboard_Radial_Capacitor_P2.54
C3: 100nF; Perfboard_Radial_Capacitor_P2.54
D1, D2, D3: 1N4148; Perfboard_Diode_DO35_P7.62
H1, H2: Perfboard_MountingHole_2.7
J1: RP23CNC 1x06 screw; Perfboard_ScrewTerminal_1x06_2.54mm
J2: PRO MICRO 1x06 screw; Perfboard_ScrewTerminal_1x06_2.54mm
R1, R2: 680R; Perfboard_Resistor_Axial_P7.62
R3, R4: 10k; Perfboard_Resistor_Axial_P7.62
R5: 390R; Perfboard_Resistor_Axial_P7.62
R6: 0R DNP; Perfboard_Resistor_Axial_P7.62
U1, U2, U3: PC817C; Perfboard_PC817_DIP4

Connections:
AUX0: D2.1, J1.4, U2.2
A_HOME: J1.5, R6.2
A_HOME_SW: R6.1, U3.4
CTRL_5V: J1.1, R1.1, R2.1
CTRL_GND: J1.2, U3.3
ENA: D1.1, J1.3, U1.2
GP8: C1.1, J2.3, R3.1, U1.4
GP9: J2.5, R5.1
GP10: C2.1, J2.4, R4.1, U2.4
LED1_A: D1.2, R1.2, U1.1
LED2_A: D2.2, R2.2, U2.1
LED3_A: D3.2, R5.2, U3.1
TOOL_3V3: C3.1, J2.1, R3.2, R4.2
TOOL_GND: C1.2, C2.2, C3.2, D3.1, J2.2, U1.3, U2.3, U3.2

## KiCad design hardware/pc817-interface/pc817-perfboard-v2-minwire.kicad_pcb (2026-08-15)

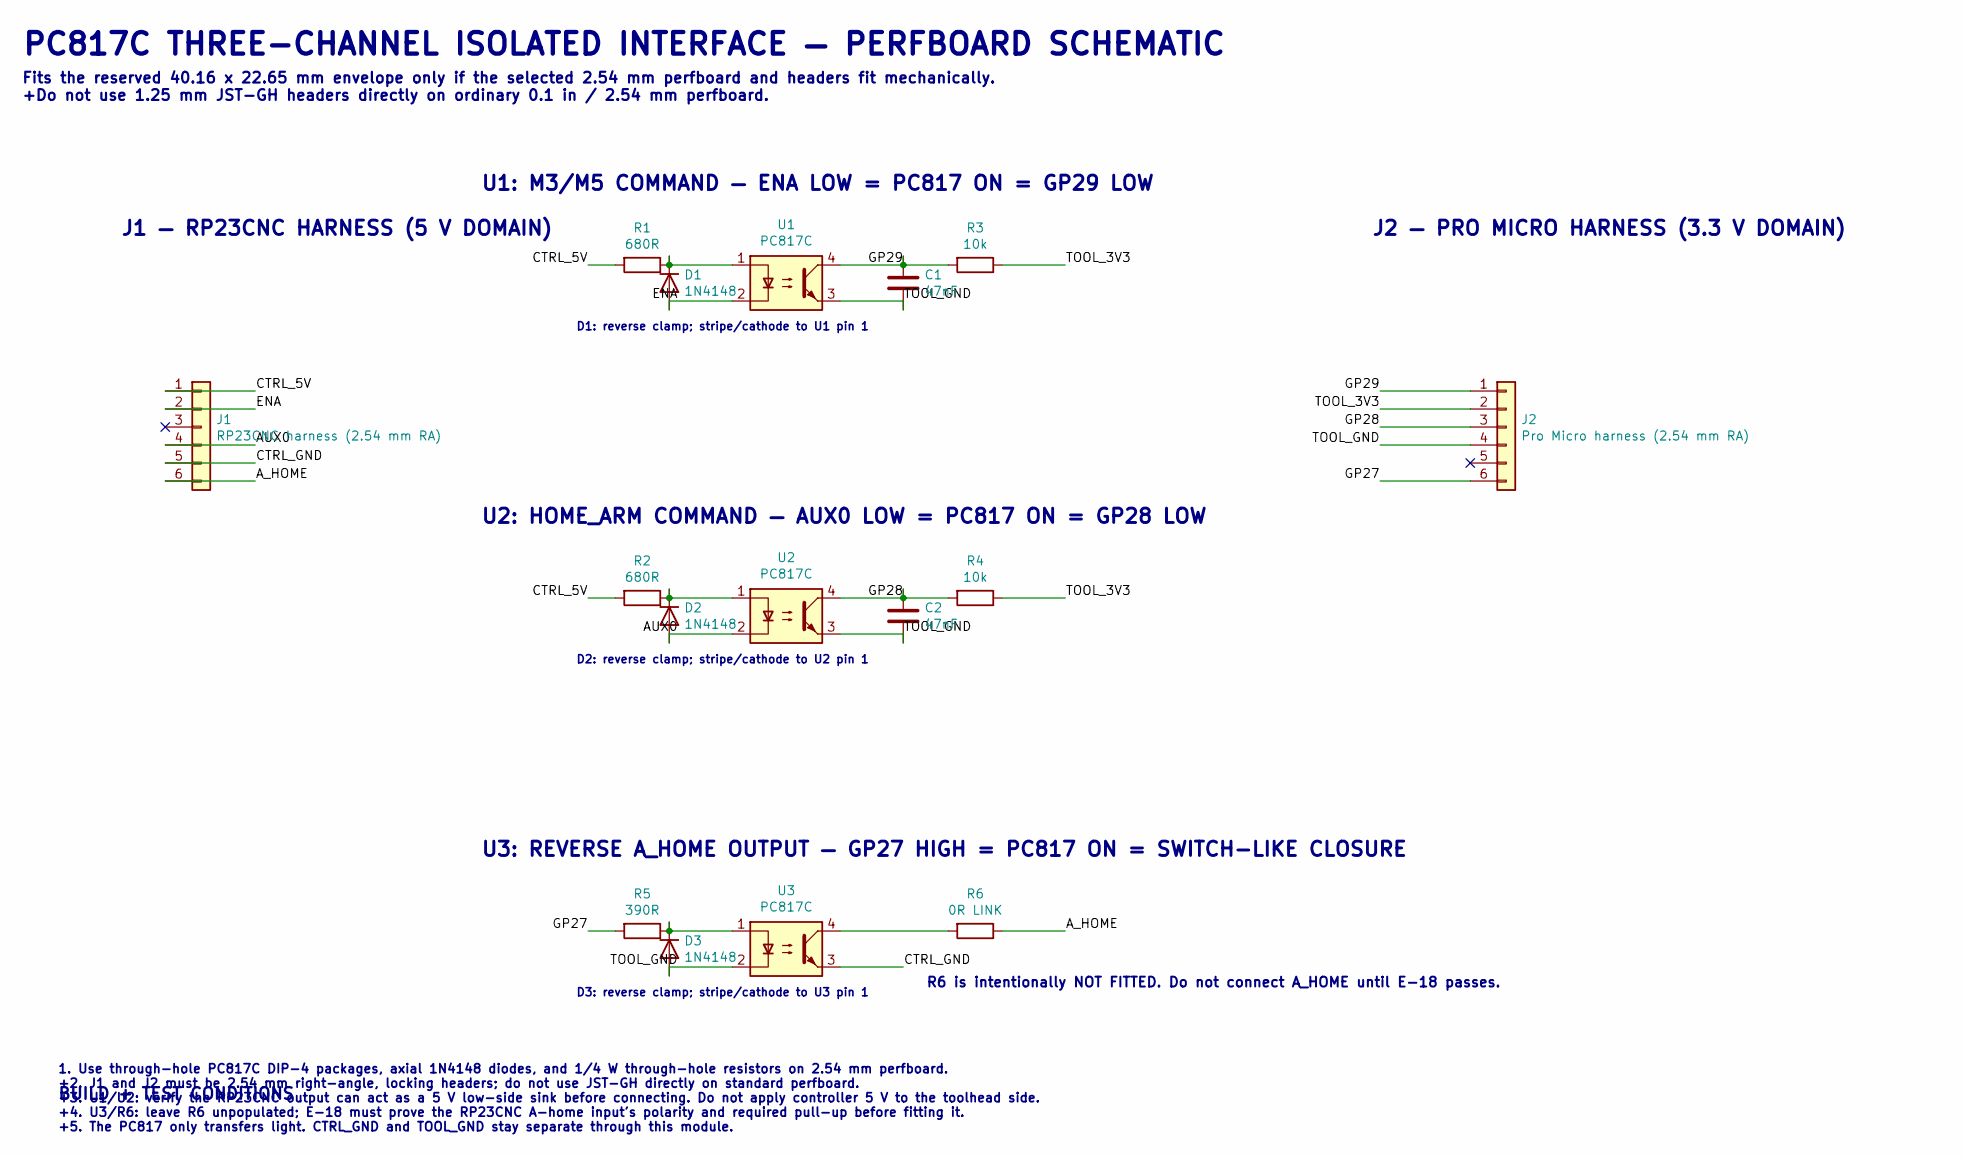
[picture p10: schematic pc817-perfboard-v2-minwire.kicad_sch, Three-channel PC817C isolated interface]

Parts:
C1, C2: 47nF
D1, D2, D3: 1N4148; D_DO-35_SOD27_P10.16mm_Horizontal
J1: RP23CNC harness (2.54 mm RA)
J2: Pro Micro harness (2.54 mm RA)
R1, R2: 680R
R3, R4: 10k
R5: 390R
R6: 0R LINK
U1, U2, U3: PC817C; DIP-4_W7.62mm

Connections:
AUX0: D2.2 (A), J1.4, U2.2
A_HOME: J1.6, R6.1
A_HOME_SW: R6.2, U3.4
CTRL_5V: J1.1, R1.2, R2.2
CTRL_GND: J1.5, U3.3
ENA: D1.2 (A), J1.2, U1.2
GP27: J2.6, R5.2
GP28: C2.1, J2.3, R4.2, U2.4
GP29: C1.1, J2.1, R3.2, U1.4
LED1_A: D1.1 (K), R1.1, U1.1
LED2_A: D2.1 (K), R2.1, U2.1
LED3_A: D3.1 (K), R5.1, U3.1
TOOL_3V3: J2.2, R3.1, R4.1
TOOL_GND: C1.2, C2.2, D3.2 (A), J2.4, U1.3, U2.3, U3.2

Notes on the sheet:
D2: reverse clamp; stripe/cathode to U2 pin 1
R6 is intentionally NOT FITTED. Do not connect A_HOME until E-18 passes.
U3: REVERSE A_HOME OUTPUT — GP27 HIGH = PC817 ON = SWITCH-LIKE CLOSURE
BUILD + TEST CONDITIONS
1. Use through-hole PC817C DIP-4 packages, axial 1N4148 diodes, and 1/4 W through-hole resistors on 2.54 mm perfboard. +2. J1 and J2 must be 2.54 mm right-angle, locking headers; do not use JST-GH directly on standard perfboard. +3. U1/U2: verify the RP23CNC output can act as a 5 V low-side sink be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
D3: reverse clamp; stripe/cathode to U3 pin 1
D1: reverse clamp; stripe/cathode to U1 pin 1
U2: HOME_ARM COMMAND — AUX0 LOW = PC817 ON = GP28 LOW
PC817C THREE-CHANNEL ISOLATED INTERFACE — PERFBOARD SCHEMATIC
J2 — PRO MICRO HARNESS (3.3 V DOMAIN)
J1 — RP23CNC HARNESS (5 V DOMAIN)
Fits the reserved 40.16 x 22.65 mm envelope only if the selected 2.54 mm perfboard and headers fit mechanically. +Do not use 1.25 mm JST-GH headers directly on ordinary 0.1 in / 2.54 mm perfboard.
U1: M3/M5 COMMAND — ENA LOW = PC817 ON = GP29 LOW

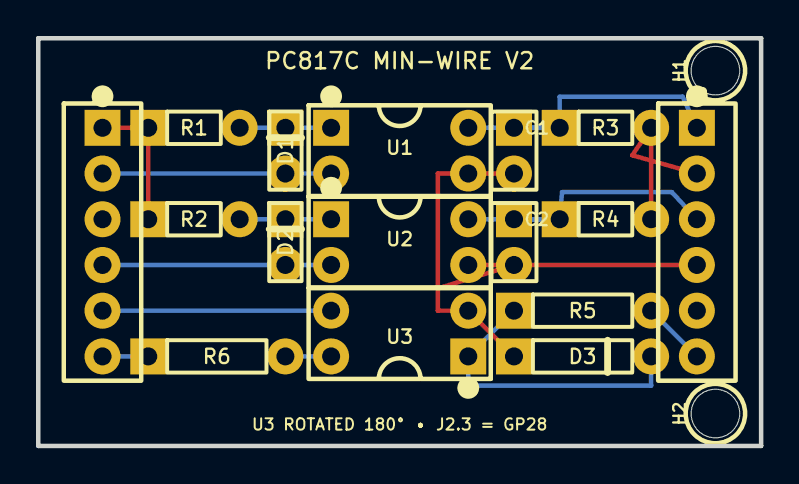
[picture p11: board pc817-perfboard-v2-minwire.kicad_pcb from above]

Board: 2 copper layers, 40.2 x 22.6 mm, 18 parts (0 on the bottom side), 14 nets.

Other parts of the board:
H1, H2: Perfboard_MountingHole_2.7

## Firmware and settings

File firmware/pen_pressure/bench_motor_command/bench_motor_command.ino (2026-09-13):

/*
  Theta plotter toolhead motor and command bench sketch

  Target: SparkFun Pro Micro RP2350 using the Arduino-Pico board package.

  Purpose:
    Test only the RP23CNC M3/M5 command input and DRV8833 motor wiring.
    This sketch does not use HX711 or TMAG5273 libraries.

  Prototype wiring:
    GP29 <- RP23CNC M3/M5 spindle-enable signal after PC817C isolation
    GP4  -> DRV8833 IN1
    GP5  -> DRV8833 IN2
    GP6  -> confirmed DRV8833 EEP / low-true nSLEEP input
    GP7  <- confirmed DRV8833 ULT / protection-fault output

  Bench with the motor mechanically unloaded until direction is verified.
*/

#include <Arduino.h>

static const uint8_t PIN_CMD_M3M5 = 29;    // GP29 / A3, protected digital input
static const uint8_t PIN_DRV_IN1 = 4;      // GP4
static const uint8_t PIN_DRV_IN2 = 5;      // GP5
// These match the installed, continuity-checked harness. Do not rewire it.
static const uint8_t PIN_DRV_SLEEP = 6;    // GP6, EEP / low-true nSLEEP
static const uint8_t PIN_DRV_FAULT = 7;    // GP7, ULT / protection fault

static const bool CMD_ACTIVE_HIGH_IS_M3 = true;
static const bool DRV_FAULT_ACTIVE_LOW = true;

// Flip these after the first motor-only bench test if direction is backward.
static const bool LIFT_USES_IN1_PWM = true;
static const bool DOWN_USES_IN1_PWM = false;

static const uint8_t PWM_STOP = 0;
static const uint8_t PWM_LIFT = 70;
static const uint8_t PWM_DOWN = 55;
static const uint32_t SERIAL_BAUD = 115200;
static const uint32_t TELEMETRY_PERIOD_MS = 250;
static const uint32_t AUTO_PULSE_MS = 300;

enum class BenchMode : uint8_t {
  AUTO_FROM_COMMAND,
  MANUAL_LIFT,
  MANUAL_DOWN,
  MANUAL_STOP
};

BenchMode mode = BenchMode::AUTO_FROM_COMMAND;
bool lastCommandEngage = false;
uint32_t autoPulseStartMs = 0;
uint32_t lastTelemetryMs = 0;

const char *modeName(BenchMode value) {
  switch (value) {
    case BenchMode::AUTO_FROM_COMMAND: return "AUTO_FROM_COMMAND";
    case BenchMode::MANUAL_LIFT: return "MANUAL_LIFT";
    case BenchMode::MANUAL_DOWN: return "MANUAL_DOWN";
    case BenchMode::MANUAL_STOP: return "MANUAL_STOP";
  }
  return "UNKNOWN";
}

void driverEnable(bool enable) {
  digitalWrite(PIN_DRV_SLEEP, enable ? HIGH : LOW);
}

void motorStop() {
  analogWrite(PIN_DRV_IN1, PWM_STOP);
  analogWrite(PIN_DRV_IN2, PWM_STOP);
}

void motorCoastAndSleep() {
  motorStop();
  driverEnable(false);
}

void motorDriveDirectional(bool useIn1Pwm, uint8_t pwm) {
  driverEnable(true);
  if (useIn1Pwm) {
    analogWrite(PIN_DRV_IN1, pwm);
    analogWrite(PIN_DRV_IN2, 0);
  } else {
    analogWrite(PIN_DRV_IN1, 0);
    analogWrite(PIN_DRV_IN2, pwm);
  }
}

void motorLift() {
  motorDriveDirectional(LIFT_USES_IN1_PWM, PWM_LIFT);
}

void motorDown() {
  motorDriveDirectional(DOWN_USES_IN1_PWM, PWM_DOWN);
}

bool driverFaulted() {
  int raw = digitalRead(PIN_DRV_FAULT);
  return DRV_FAULT_ACTIVE_LOW ? (raw == LOW) : (raw == HIGH);
}

bool commandRequestsEngage() {
  int raw = digitalRead(PIN_CMD_M3M5);
  return CMD_ACTIVE_HIGH_IS_M3 ? (raw == HIGH) : (raw == LOW);
}

void printTelemetry() {
  Serial.print(F("mode="));
  Serial.print(modeName(mode));
  Serial.print(F(" gp29_cmd="));
  Serial.print(commandRequestsEngage() ? F("M3/ENGAGE") : F("M5/LIFT"));
  Serial.print(F(" fault="));
  Serial.print(driverFaulted() ? F("1") : F("0"));
  Serial.print(F(" in1="));
  Serial.print(digitalRead(PIN_DRV_IN1));
  Serial.print(F(" in2="));
  Serial.print(digitalRead(PIN_DRV_IN2));
  Serial.print(F(" sleep="));
  Serial.println(digitalRead(PIN_DRV_SLEEP));
}

void printHelp() {
  Serial.println();
  Serial.println(F("Theta motor/command bench commands:"));
  Serial.println(F("  ?  print this help"));
  Serial.println(F("  p  print telemetry now"));
  Serial.println(F("  a  automatic GP29 command input"));
  Serial.println(F("  u  run lift direction"));
  Serial.println(F("  d  run down direction"));
  Serial.println(F("  s  stop motor"));
  Serial.println(F("In AUTO, a GP29 M3 transition gives a short down pulse; M5 gives a short lift pulse."));
  Serial.println();
}

void serviceSerial() {
  while (Serial.available() > 0) {
    char c = static_cast<char>(Serial.read());
    switch (c) {
      case '?':
        printHelp();
        break;
      case 'p':
        printTelemetry();
        break;
      case 'a':
        mode = BenchMode::AUTO_FROM_COMMAND;
        autoPulseStartMs = millis();
        Serial.println(F("Mode: automatic GP29 input"));
        break;
      case 'u':
        mode = BenchMode::MANUAL_LIFT;
        Serial.println(F("Mode: manual lift"));
        break;
      case 'd':
        mode = BenchMode::MANUAL_DOWN;
        Serial.println(F("Mode: manual down"));
        break;
      case 's':
        mode = BenchMode::MANUAL_STOP;
        motorStop();
        Serial.println(F("Mode: manual stop"));
        break;
      default:
        break;
    }
  }
}

void serviceMotor() {
  if (driverFaulted()) {
    motorStop();
    return;
  }

  switch (mode) {
    case BenchMode::MANUAL_LIFT:
      motorLift();
      break;

    case BenchMode::MANUAL_DOWN:
      motorDown();
      break;

    case BenchMode::MANUAL_STOP:
      motorStop();
      break;

    case BenchMode::AUTO_FROM_COMMAND: {
      const bool engage = commandRequestsEngage();
      const uint32_t now = millis();
      if (engage != lastCommandEngage) {
        lastCommandEngage = engage;
        autoPulseStartMs = now;
        Serial.print(F("GP29 command changed: "));
        Serial.println(engage ? F("M3/ENGAGE") : F("M5/LIFT"));
      }

      if (now - autoPulseStartMs <= AUTO_PULSE_MS) {
        if (engage) {
          motorDown();
        } else {
          motorLift();
        }
      } else {
        motorStop();
      }
      break;
    }
  }
}

void setup() {
  pinMode(PIN_CMD_M3M5, INPUT_PULLDOWN);
  pinMode(PIN_DRV_IN1, OUTPUT);
  pinMode(PIN_DRV_IN2, OUTPUT);
  pinMode(PIN_DRV_SLEEP, OUTPUT);
  pinMode(PIN_DRV_FAULT, INPUT_PULLUP);

  motorCoastAndSleep();

  Serial.begin(SERIAL_BAUD);
  delay(500);
  Serial.println();
  Serial.println(F("Theta motor/command bench sketch"));
  lastCommandEngage = commandRequestsEngage();
  autoPulseStartMs = millis();
  printHelp();
}

void loop() {
  const uint32_t now = millis();

  serviceSerial();
  serviceMotor();

  if (now - lastTelemetryMs >= TELEMETRY_PERIOD_MS) {
    lastTelemetryMs = now;
    printTelemetry();
  }
}

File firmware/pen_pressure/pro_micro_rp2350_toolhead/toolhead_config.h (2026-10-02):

#pragma once

#include <Arduino.h>

namespace toolhead_config {

// Installed pin map. Keep synchronized with docs/hardware/WIRING_TABLE.md.
constexpr uint8_t PIN_CMD_M3M5 = 29;
constexpr uint8_t PIN_A_HOME_OUT = 27;
constexpr uint8_t PIN_HOME_ARM_IN = 28;
constexpr uint8_t PIN_LIFT_HOME = 2;
constexpr uint8_t PIN_DRV_IN1 = 4;
constexpr uint8_t PIN_DRV_IN2 = 5;
// Confirmed installed module: EEP is nSLEEP and ULT is nFAULT.
constexpr uint8_t PIN_DRV_SLEEP = 6;
constexpr uint8_t PIN_DRV_FAULT = 7;
// CS1238 channel-A two-wire ADC interface. The physical GP0/GP1 harness is
// retained from the former HX711 path, but the ADC protocol is different.
constexpr uint8_t PIN_CS1238_DT = 0;
constexpr uint8_t PIN_CS1238_SCK = 1;
constexpr uint8_t PIN_I2C_SDA = 16;
constexpr uint8_t PIN_I2C_SCL = 17;
constexpr uint8_t PIN_SERVICE_UART_TX = 20;
constexpr uint8_t PIN_SERVICE_UART_RX = 21;

constexpr bool CMD_ACTIVE_HIGH_IS_M3 = false;
constexpr bool HOME_ARM_ACTIVE_LOW = true;
// GP2 raw input is LOW when pressed; liftHomeActive() reports that semantic
// state as lift_home=1 (released reports 0).
constexpr bool LIFT_HOME_ACTIVE_LOW = true;
constexpr bool DRV_FAULT_ACTIVE_LOW = true;
// E-09E direction evidence: IN1 HIGH / IN2 LOW drives DOWN; IN1 LOW /
// IN2 HIGH drives UP. The booleans select which phase receives PWM.
constexpr bool LIFT_USES_IN1_PWM = false;
constexpr bool SEEK_USES_IN1_PWM = true;

// E-09E uses full phase drive for the validated 5–100 ms UP pulses. The
// integrated controller must overcome the installed mechanism's static
// friction before its GP2 maximum-retract guard can assert.
constexpr uint8_t PWM_LIFT = 255;
constexpr uint8_t PWM_SEEK = 55;

// The hard retract switch can preload the mechanism. After M3 first leaves
// GP2, stop and let it settle before sampling the clear-of-paper tare.
constexpr uint32_t HOME_RELEASE_TARE_SETTLE_MS = 1000;

constexpr uint32_t SERIAL_BAUD = 115200;
// Boot/fault recovery drives UP continuously and stops immediately when GP2
// reports the pressed/home state. This timeout is the independent runaway
// bound if GP2 never asserts; it is not the normal M5 air-gap duration.
constexpr uint32_t BOOT_LIFT_TIME_MS = 3000;
constexpr uint32_t LIFT_VERIFY_TIMEOUT_MS = 1800;
constexpr uint32_t PEN_CLEAR_RELEASE_TIMEOUT_MS = 1800;
// Clearance air gap. E-09F measured about 1.75 mm per 100 ms of UP drive, so
// 70 ms targets about 1.2 mm. The gap sets how far the next M3 must travel and
// is folded into the warm-seek moving average; it must remain larger than
// paper/bed height variation or the pen drags during pen-up travel.
//
// 2026-10-02: raised 57 -> 70 ms. The operator reported drag marks during
// pen-up travel on production prints at the T-01H-accepted 57 ms, so the
// clearance value is re-opened pending the next no-drag run.
constexpr uint32_t PEN_CLEAR_EXTRA_LIFT_MS = 70;
// Normal M5 changes the mechanism's unloaded CS1238 baseline. Once the
// clearance motion has stopped, wait for the full sensing settle before
// taking the 64-sample clear-state tare. E-09F showed that a 50 ms read is
// still inside the post-drive mechanical transient.
// 2026-09-23 E-09E settle trace, three 5 ms DOWN pulses with the pen clear:
// the 16-sample filtered value reached within about +/-1,000 raw of its
// plateau at 218 / 220 / 294 ms, against a 300-692 raw tail noise floor.
// 300 ms covers that at roughly 1.5x the noise; 500 ms was a borrowed value.
constexpr uint32_t PEN_CLEAR_TARE_SETTLE_MS = 300;
// Supervised bench build: home to GP2 at startup, use a slow bounded seek when
// M3 begins at GP2, and retain the measured 100 ms M3/M5 pair between strokes.
// This is not the production commissioning gate.
constexpr bool MECHANICAL_PRELOAD_MODE = true; // supervised bench test build
constexpr uint32_t PEN_ENGAGE_TRAVEL_MS = 100;
constexpr uint32_t SEEK_TIMEOUT_MS = 1500;
// Use a bounded coarse pulse only while the pen is still clearly airborne, then
// switch to fine pulses before the 40 g contact threshold. A 25 ms pulse moved
// about 0.44 mm and the 2026-09-24 carriage-swap run reproduced the then-60 g
// trip with 60.1 g two coarse pulses into a warm seek. A 10 ms pulse moves about
// 0.18 mm, so a worst-case placement lands near the 40 g target rather than
// through the 75 g limit, while still covering ~2x a fine pulse so the seek
// stays faster than fine-only.
constexpr uint8_t HOME_SEEK_COARSE_PULSE_MS = 10;
constexpr uint8_t HOME_SEEK_FINE_PULSE_MS = 5;
constexpr uint8_t HOME_SEEK_FINE_THRESHOLD_DIVISOR = 5;
// Force must be read only after the pulse has settled. E-09F's 500 ms settle
// produced repeatable 40.0 g / 40.4 g holds on this mechanism, where 50 ms
// reads were still settling transients. The 2026-09-23 E-09E settle trace
// measured the filtered value reaching +/-1,000 raw of its plateau by
// 218 / 220 / 294 ms, so 300 ms covers the measured settle.
constexpr uint32_t HOME_SEEK_SETTLE_MS = 300;
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

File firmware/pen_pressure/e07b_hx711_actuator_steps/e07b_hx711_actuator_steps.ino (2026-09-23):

/*
  E-07B: HX711 telemetry with safe N20 actuator steps

  This sketch uses an externally connected USB-to-TTL adapter for the serial
  console. It is intended for use while the toolhead runs from its normal 6 V
  supply, so the Pro Micro USB-C port MUST remain unplugged after upload.

  USB-to-TTL adapter wiring (adapter logic level set to 3.3 V):
    Adapter GND -> Pro Micro TOOL_GND
    Adapter RXD <- Pro Micro GP20 (UART1 TX)
    Adapter TXD -> Pro Micro GP21 (UART1 RX)
    Adapter VCC -> NOT CONNECTED

  Toolhead wiring:
    GP0 <- HX711 DT/DOUT                 GP4 -> DRV8833 IN1
    GP1 -> HX711 SCK                     GP5 -> DRV8833 IN2
    Pro Micro 3V3 -> HX711 VCC           GP6 -> DRV8833 EEP sleep
    Pro Micro GND -> HX711 GND           GP7 <- DRV8833 ULT fault
    GP2 <- LIFT_HOME normally-open switch to TOOL_GND

  Commands at 115200 baud:
    t  tare the unloaded, stationary mechanism (20 samples)
    p  print one HX711 reading now
    d  one selected-duration pen-DOWN step, then driver sleeps
    u  one selected-duration pen-UP step, then driver sleeps
    a  automatic approach: 50 ms DOWN pulses until load is detected
    r  fast 12-down/12-up trace at 10 ms per pulse; tare while clear first
    [  reduce step time: 10 ms steps at or below 100 ms, otherwise 100 ms
    ]  increase step time: 10 ms steps below 100 ms, otherwise 100 ms
    x  stop and sleep driver immediately
    h  report LIFT_HOME switch state
    v  60-second meter-mode sequence; no motor motion
    o  60-second OUT1/OUT2 meter sequence; motor must be disconnected
    ?  print help

  Do not use continuous motor commands for E-07B. Place a digital scale under
  the pen, tare while clear of the scale, and use one short step at a time.
  Keep the first calibration below 1 N / 100 g and below the load cell's
  300 g rating.
*/

#include <Arduino.h>
#include "HX711.h"

constexpr uint8_t PIN_HX711_DT = 0;
constexpr uint8_t PIN_HX711_SCK = 1;
constexpr uint8_t PIN_IN1 = 4;
constexpr uint8_t PIN_IN2 = 5;
// The confirmed installed module labels EEP as nSLEEP and ULT as nFAULT.
constexpr uint8_t PIN_DRV_SLEEP = 6;
constexpr uint8_t PIN_DRV_FAULT = 7;
constexpr uint8_t PIN_LIFT_HOME = 2;
constexpr uint8_t PIN_UART_TX = 20;
constexpr uint8_t PIN_UART_RX = 21;

constexpr uint32_t SERIAL_BAUD = 115200;
constexpr uint8_t TARE_SAMPLES = 20;
constexpr uint16_t STEP_MIN_MS = 10;
constexpr uint16_t STEP_FINE_LIMIT_MS = 100;
// E07B has no motion-controlled LIFT_HOME stop, so this is a guard rather
// than a 100 ms tuning restriction. Use only the shortest pulse that produces
// the required observation and keep clear travel to the selected direction.
constexpr uint16_t STEP_MAX_MS = 1000;
constexpr uint16_t STEP_FINE_INCREMENT_MS = 10;
constexpr uint16_t STEP_COARSE_INCREMENT_MS = 100;
constexpr uint16_t AUTO_APPROACH_STEP_MS = 50;
constexpr uint16_t METER_HOLD_MS = 30000;
constexpr uint8_t AUTO_APPROACH_MAX_STEPS = 20;
constexpr uint8_t AUTO_APPROACH_LEARN_STEPS = 3;
constexpr uint8_t TRACE_STEPS_PER_DIRECTION = 12;
constexpr uint16_t TRACE_STEP_MS = 10;
// Raised from the original 500 ms across several bench iterations
// (500 -> ~1200 -> ~1690 -> ~2620 -> 4000 ms) because the external scale's
// own settle behavior and the mechanism's backlash/creep were not resolved
// at the shorter dwells, which made per-pulse video readings unreliable.
// At 4000 ms, individual pulses finally showed up on video as discrete
// steps with a flat hold between them; one such step pair was matched with
// high confidence against the corresponding UP-phase log deltas. See
// docs/report/lab-notes and this folder's trace-settle-ms tuning note for
// the evidence. This is a diagnostic dwell for bench characterization, not
// a chosen production hold time.
constexpr uint16_t TRACE_SETTLE_MS = 4000;
// The installed load cell also sees normal lead-screw/mechanism force while
// traveling. Stop only when one pulse departs substantially from that learned
// no-contact behavior; this is roughly 10 g in the 57.2 g bench experiments.
constexpr long AUTO_CONTACT_RESIDUAL_COUNTS = 50000;
constexpr bool DRV_FAULT_ACTIVE_LOW = true;

// Verified with the installed 1000 RPM N20: IN1 LOW drives pen-up/lift and
// IN1 HIGH drives pen-down/lower. Keep the motor wires in their present state.
constexpr bool LIFT_IN1_HIGH = false;
constexpr bool LOWER_IN1_HIGH = true;

HX711 scale;
long tareRaw = 0;
long lastRaw = 0;
uint16_t stepMs = 20;
bool tareValid = false;

bool faultActive() {
  return digitalRead(PIN_DRV_FAULT) == (DRV_FAULT_ACTIVE_LOW ? LOW : HIGH);
}

bool liftHomePressed() {
  return digitalRead(PIN_LIFT_HOME) == LOW;
}

void reportLiftHome() {
  Serial2.print(F("lift_home="));
  Serial2.println(liftHomePressed() ? F("1") : F("0"));
}

void stopAndSleep() {
  digitalWrite(PIN_IN1, LOW);
  digitalWrite(PIN_IN2, LOW);
  digitalWrite(PIN_DRV_SLEEP, LOW);
}

bool readRaw(long &value) {
  if (!scale.is_ready()) return false;
  value = scale.read();
  lastRaw = value;
  return true;
}

void report() {
  long raw = lastRaw;
  const bool ready = readRaw(raw);
  Serial2.print(F("hx_ready="));
  Serial2.print(ready ? F("1") : F("0"));
  Serial2.print(F(" hx_raw="));
  Serial2.print(lastRaw);
  Serial2.print(F(" hx_tare="));
  Serial2.print(tareRaw);
  Serial2.print(F(" hx_delta="));
  Serial2.println(lastRaw - tareRaw);
}

void tare() {
  long total = 0;
  uint8_t count = 0;

  stopAndSleep();
  Serial2.println(F("Taring: leave pen clear of scale and mechanism still."));
  while (count < TARE_SAMPLES) {
    long sample = 0;
    if (readRaw(sample)) {
      total += sample;
      count++;
    }
    delay(10);
  }
  tareRaw = total / TARE_SAMPLES;
  tareValid = true;
  Serial2.print(F("Tare raw="));
  Serial2.println(tareRaw);
}

void moveOneStep(bool in1High, const __FlashStringHelper *name) {
  stopAndSleep();
  if (faultActive()) {
    Serial2.println(F("ULT reports FAULT; motor command cancelled."));
    return;
  }

  Serial2.print(name);
  Serial2.print(F(" step: "));
  Serial2.print(stepMs);
  Serial2.println(F(" ms"));

  digitalWrite(PIN_DRV_SLEEP, HIGH);
  delay(5);
  if (faultActive()) {
    Serial2.println(F("ULT reports FAULT after driver enable; motor command cancelled."));
    stopAndSleep();
    return;
  }
  digitalWrite(PIN_IN1, in1High ? HIGH : LOW);
  digitalWrite(PIN_IN2, in1High ? LOW : HIGH);
  delay(stepMs);
  const int faultRawDuringDrive = digitalRead(PIN_DRV_FAULT);
  const bool faultDuringDrive = DRV_FAULT_ACTIVE_LOW ?
      faultRawDuringDrive == LOW : faultRawDuringDrive == HIGH;
  stopAndSleep();
  Serial2.print(F("Motor stopped and asleep; fault_during_drive="));
  Serial2.print(faultDuringDrive ? F("1") : F("0"));
  Serial2.print(F(" raw="));
  Serial2.print(faultRawDuringDrive);
  Serial2.print(F("; "));
  reportLiftHome();
}
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

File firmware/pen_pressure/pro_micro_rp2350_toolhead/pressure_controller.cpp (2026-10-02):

#include "pressure_controller.h"

#include <cstdlib>

#include "contact_seek_policy.h"
#include "toolhead_config.h"
#include "toolhead_shared.h"

using namespace toolhead_config;

void PressureController::begin() {
  pinMode(PIN_CMD_M3M5, INPUT);
  pinMode(PIN_DRV_IN1, OUTPUT);
  pinMode(PIN_DRV_IN2, OUTPUT);
  pinMode(PIN_DRV_SLEEP, OUTPUT);
  pinMode(PIN_DRV_FAULT, INPUT_PULLUP);
  pinMode(PIN_LIFT_HOME, INPUT_PULLUP);

  motorStop();
  setDriverEnabled(false);

  if (!scale_.begin() ||
      !scale_.setConfig(CS123X_CH_A, CS123X_GAIN_128, CS123X_RATE_640Hz, true)) {
    enterFault("CS1238 initialization/configuration failed");
    return;
  }
  state_started_ms_ = millis();
  setStatusFlag(STATUS_CORE0_READY, true);

  if (!ACTUATOR_DIRECTION_VALID) {
    enterFault("T-01 actuator direction is not commissioned");
    return;
  }

  setState(PressureState::LIFTING);
}

const char *PressureController::stateName() const {
  switch (state_) {
    case PressureState::BOOT: return "BOOT";
    case PressureState::LIFTING: return "LIFTING";
    case PressureState::HOME_RELEASE_TARE_SETTLING:
      return "HOME_RELEASE_TARE_SETTLING";
    case PressureState::VERIFY_LIFTED: return "VERIFY_LIFTED";
    case PressureState::LIFTED: return "LIFTED";
    case PressureState::MECHANICAL_ENGAGE: return "MECHANICAL_ENGAGE";
    case PressureState::HOME_SEEK_CONTACT: return "HOME_SEEK_CONTACT";
    case PressureState::SEEK_CONTACT: return "SEEK_CONTACT";
    case PressureState::HOLD_FORCE: return "HOLD_FORCE";
    case PressureState::RELEASE_TO_CLEAR: return "RELEASE_TO_CLEAR";
    case PressureState::CLEARANCE_LIFT: return "CLEARANCE_LIFT";
    case PressureState::CLEAR_TARE_SETTLING: return "CLEAR_TARE_SETTLING";
    case PressureState::FAULT: return "FAULT";
  }
  return "UNKNOWN";
}

void PressureController::setState(PressureState next) {
  state_ = next;
  state_started_ms_ = millis();
  if (next != PressureState::VERIFY_LIFTED) {
    lift_release_windows_ = 0;
  }
  if (next != PressureState::HOLD_FORCE) {
    contact_ready_windows_ = 0;
    contact_ready_lost_since_ms_ = 0;
    hold_correction_pulse_active_ = false;
    hold_out_of_band_windows_ = 0;
    hold_out_of_band_direction_ = 0;
    hold_out_of_band_last_ms_ = 0;
    hold_urgent_relief_active_ = false;
  }
  if (next != PressureState::HOME_SEEK_CONTACT) {
    home_seek_pulse_active_ = false;
    home_seek_active_pulse_ms_ = 0;
  }
  if (next != PressureState::HOME_RELEASE_TARE_SETTLING) {
    home_tare_sampling_started_ = false;
  }
  if (next != PressureState::CLEAR_TARE_SETTLING) {
    clear_tare_sampling_started_ = false;
  }
  publishSafetyState();
}

void PressureController::setDriverEnabled(bool enabled) {
  digitalWrite(PIN_DRV_SLEEP, enabled ? HIGH : LOW);
  if (!enabled) {
    motor_driving_ = false;
  }
}

void PressureController::motorStop() {
  analogWrite(PIN_DRV_IN1, 0);
  analogWrite(PIN_DRV_IN2, 0);
  motor_driving_ = false;
}

void PressureController::motorDrive(bool use_in1_pwm, uint8_t pwm) {
  setDriverEnabled(true);
  if (use_in1_pwm) {
    analogWrite(PIN_DRV_IN1, pwm);
    analogWrite(PIN_DRV_IN2, 0);
  } else {
    analogWrite(PIN_DRV_IN1, 0);
    analogWrite(PIN_DRV_IN2, pwm);
  }
  motor_driving_ = true;
}

void PressureController::motorLift() {
  motorDrive(LIFT_USES_IN1_PWM, PWM_LIFT);
}

void PressureController::motorSeek() {
  motorDrive(SEEK_USES_IN1_PWM, PWM_SEEK);
}

bool PressureController::driverFaulted() const {
  const int raw = digitalRead(PIN_DRV_FAULT);
  return DRV_FAULT_ACTIVE_LOW ? raw == LOW : raw == HIGH;
}

bool PressureController::liftHomeActive() const {
  const int raw = digitalRead(PIN_LIFT_HOME);
  return LIFT_HOME_ACTIVE_LOW ? raw == LOW : raw == HIGH;
}

bool PressureController::commandEngage() const {
  if (manual_override_) {
    return manual_engage_;
  }
  const int raw = digitalRead(PIN_CMD_M3M5);
  return CMD_ACTIVE_HIGH_IS_M3 ? raw == HIGH : raw == LOW;
}

long PressureController::normalizedForceDelta() const {
  return static_cast<long>(CS1238_CONTACT_FORCE_SIGN) * forceDelta();
}

long PressureController::activeTargetForceRaw() const {
  const long requested = TARGET_FORCE_RAW_DELTA;
  // The top of the acceptance band must always keep HOLD_BAND_HEADROOM_RAW
  // below the absolute hard-force limit.
  constexpr long max_target =
      HARD_FORCE_RAW_DELTA - CONTACT_READY_TOLERANCE_RAW - HOLD_BAND_HEADROOM_RAW;
  return requested < max_target ? requested : max_target;
}

long PressureController::activeHardForceRaw() const {
  // The hard-force guard is always the configured absolute 75 g envelope; no
  // target, reference, or clamp may enlarge it.
  return HARD_FORCE_RAW_DELTA;
}

long PressureController::noContactResidual() const {
  // The E-09C zero is retained in configuration as calibration evidence, but
  // every boot takes a fresh unloaded tare. Clear detection must use that live
  // reference so an otherwise valid profile is not defeated by ADC drift or a
  // small fixture-zero change.
  return cs1238_filtered_ - cs1238_tare_;
}

void PressureController::updateFilteredSample(long sample) {
  if (sample_window_count_ == CS1238_MOVING_AVERAGE_SAMPLES) {
    sample_window_sum_ -= sample_window_[sample_window_index_];
  } else {
    sample_window_count_++;
  }
  sample_window_[sample_window_index_] = sample;
  sample_window_sum_ += sample;
  sample_window_index_ = (sample_window_index_ + 1) % CS1238_MOVING_AVERAGE_SAMPLES;
  if (sample_window_count_ < CS1238_MOVING_AVERAGE_SAMPLES) {
    return;
  }
  cs1238_filtered_ = static_cast<long>(sample_window_sum_ / CS1238_MOVING_AVERAGE_SAMPLES);
  new_filtered_sample_ = true;
}

void PressureController::serviceTare(long sample) {
  if (!tare_requested_) {
    return;
  }
  tare_sum_ += sample;
  tare_count_++;
  if (tare_count_ >= CS1238_TARE_SAMPLES) {
    cs1238_tare_ = static_cast<long>(tare_sum_ / tare_count_);
    tare_requested_ = false;
    tare_valid_ = true;
    tare_sum_ = 0;
    tare_count_ = 0;
  }
}
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

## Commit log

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2026-09-08 fix: mirror lift-home telemetry to service uart
    [pro_micro_rp2350_toolhead.ino, toolhead_config.h]
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2026-09-08 fix: use uart1 for toolhead service pins
    [pro_micro_rp2350_toolhead.ino, t01g_lift_home_uart.ino]
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2026-09-09 fix: restore integrated toolhead UART telemetry
    [pro_micro_rp2350_toolhead.ino]
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2026-09-13 Correct toolhead DRV8833 sleep fault mapping
    [bench_motor_command.ino, e05_n20_no_load.ino, e07b_hx711_actuator_steps.ino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]
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2026-09-22 Fix E09F release hard limit handling
    [e09f_cs1238_guarded_force_hold.ino]
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2026-09-22 Correct lift home telemetry polarity
    [toolhead_config.h]
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2026-09-22 Correct integrated motor direction polarity
    [toolhead_config.h]
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2026-09-22 Reacquire pen contact after clearance
    [pressure_controller.cpp, pressure_controller.h]
2026-09-22 Trend-gate pen hold corrections
    [pressure_controller.cpp, pressure_controller.h, toolhead_config.h]
2026-09-22 Tare pen force after normal clearance
    [pressure_controller.cpp, pressure_controller.h, toolhead_config.h]
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2026-09-23 Replace the two-touch seek with a single descend
    [pressure_controller.cpp, pressure_controller.h, pro_micro_rp2350_toolhead.ino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]
2026-09-23 Reduce the M5 clearance air gap to about 1 mm
    [toolhead_config.h]
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2026-09-23 Stabilize warm-seek travel and gate motor-driven sensor noise
    - Round the warm coarse budget to the nearest pulse instead of truncating,
    and correct the coarse-to-fine ratio (5 -> 13) with a 4-pulse reserve so
    the EMA stops oscillating between fine-only and one-coarse seeks.
    - Do not count CS1238 implausible conversions taken while the motor is
    PWM-driving toward the sensor-health fault streak; motor drive bit-bangs
    the GP0/GP1 interface and produces transient glitches.
    - Add t_ms and cs1238_last_reject to telemetry for direct latency/glitch
    visibility in the log.
    [pressure_controller.cpp, pressure_controller.h, pro_micro_rp2350_toolhead.ino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]
2026-09-23 Require a full filter window before the CS1238 implausible fault
    Three consecutive rejects is only ~4.7 ms at 640 SPS and still faulted a
    working hold on a momentary bit-bang glitch burst. Raise the streak to 16
    (one full 16-sample window) so isolated bursts are absorbed; a dead or
    disconnected sensor still faults via the read-timeout/online path.
    [pressure_controller.cpp, toolhead_config.h]
2026-09-23 Record F-05: invert the grblHAL spindle enable for the toolhead
    The RP23CNC spindle ENA output is active-high by default, which held the
    toolhead's active-low optocoupler input on at idle and made the pen dive
    whenever the controller powered up. Set \=1 (invert spindle enable) on
    the controller: M3 drives the pen down, M5 lifts it, and the pen-up
    fail-safe is preserved. No optocoupler change.
    Adds the F-05 lab note and change note RPSW-20260923-015, a verified
    grblhal/config/machine-settings.md, and updates the wiring table,
    interface contract, test plan, roadmap, and engineering log.
2026-09-23 Record T-01H clearance pass: pen clears on M5 without drag
    About 10-20 M3/M5 cycles with X/Y jogs between strokes: every M5 cleared
    the pen, the inter-stroke jog left no mark, every M3 re-contacted, and no
    cycle faulted. Validates the staged 57 ms clearance behaviorally; the
    measured pen-tip gap and 30-cycle formal record remain open, so
    PEN_CLEAR_VALID stays false.
2026-09-23 Tune first-print behavior: wider hold band and centerline strokes
    Firmware: widen the target-ready band from +/-5 g to +/-10 g (25-45 g)
    and move the urgent-relief trigger to 15 g above target so it still
    clears the wider band top. Reduces retract/re-approach churn from
    friction drift on long strokes.
    Converter: draw stroked paths as centerlines by default instead of
    outlining the stroke width. The house-and-sun sample drops from ~150
    pen-down cycles to 20, cutting M3/M5 churn and letting the force loop
    settle. Opt-in 'Expand strokes to outlines' restores the old behavior.
    Change notes RPSW-20260923-016 and WSW-20260923-001; docs updated and
    index checks pass.
    [toolhead_config.h]
2026-09-23 Fix the Qt app path that still hard-coded stroke outlining
    The desktop app's MainWindow.load_contours calls parse_svg_geometry
    directly with expand_strokes hard-coded True, bypassing the shared
    read_svg. That is the path the app actually uses, so the earlier
    centerline fix never reached the preview or export. Wire it to the
    setting and add expand_strokes to raw_geometry_key so toggling the
    checkbox invalidates the cached contours.
    Verified: the Qt contour path now yields 20 centerline contours for the
    house-and-sun (each sun ray = one line) instead of outlined rectangles.
2026-09-24 Subdivide polar draw moves so bed rotation traces straight lines
    grblHAL interpolates X/Y/A linearly across one move, and the converter
    emitted one move per SVG segment, so a move spanning bed rotation bowed
    the pen off the intended straight bed line (up to 25 mm; the house roof
    came out as a dome).
    Add polar_segment_steps, which measures each move's bed-frame bow and
    splits it so every sub-chord stays within tolerance, and emit those
    sub-moves from contours_to_gcode.
    Verified: within-stroke deviation drops to 0.24-0.25 mm for every theta
    mode; the sample still emits 20 pen-down strokes; converter tests pass.
    [gcode.py, kinematics.py]
2026-09-24 Default the converter to the installed toolhead
    The shipped defaults produced a file that did not draw: pen_down_ms 600
    was shorter than the toolhead M3 seek (~1.2 s warm, ~2.9 s from GP2),
    pen_up_ms 300 was shorter than the ~0.46 s M5 clear, and 1200 mm/min
    disturbed the force hold.
    Set feed_rate 1200 -> 700, theta_tangential_speed_mm_min 1200 -> 700,
    pen_up_ms 300 -> 800, pen_down_ms 600 -> 3500, in both the Settings
    dataclass and the UI field defaults.
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2026-09-24 Dwell the program's first pen-down for the cold seek
    The toolhead parks on the GP2 lift switch, so the first M3 has to travel the
    whole retract distance before it reaches paper - about 7 s, made of coarse
    pulses, a 1000 ms release-tare wait, a 64-sample tare, then the rest of the
    approach. Every later M3 starts from the ~1 mm M5 clearance and finishes in
    2-3 s. The converter dwelled a flat 3500 ms after every M3, so grblHAL expired
    it early and drew roughly 40-50 mm of the first stroke in the air.
    Adds Pen down first ms (pen_down_first_ms, default 10000) applied to the
    program's first M3 only. Later pen-downs keep Pen down ms = 3500, so a filled
    drawing does not pay the cold-seek margin on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
    [gcode.py]
2026-09-24 Bound the coarse seek and recover hard-limit overshoot
    After the linear-rail carriage swap, a warm seek tripped 'hard force limit
    exceeded' at 60.1 g two pulses in, with a 33-unit learned travel sizing a
    2-pulse coarse budget. A single 25 ms full-drive coarse pulse was worth more
    than the whole 60 g envelope, so the 3 g gate could not catch it.
    Shorten the coarse pulse from 25 ms to 10 ms and the warm travel ratio from
    13 to 2, so one coarse step lands near the 35 g target instead of through the
    60 g limit while still covering twice a fine pulse.
    Also make a hard-limit overshoot recoverable: instead of latching FAULT (which
    left the pen down while the gantry dragged it), lift through the n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
    [pressure_controller.cpp, pressure_controller.h, pro_micro_rp2350_toolhead.ino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]
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2026-09-25 Preview the artwork alone, not the machine path
    The rotating-bed gantry path is a tangle of short polar jogs, and the preview
    was drawing it — plus travel moves, a crosshair, and a tool marker, all in
    machine coordinates — on top of the artwork, while also rotating the artwork by
    the bed's final angle. The result read as scratch lines over the text even when
    the artwork was correct.
    paintGL now draws the bed-frame artwork upright (theta = 0) and drops the
    machine-frame motion/travel and the dynamic machine-frame markers. Playback
    progress still fills the strokes in from the undrawn color. py_compile and the
    24 converter tests pass.
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2026-09-25 Record T-01H clearance evidence from production prints
    The operator ran several complete letter prints and the pen settled clearly
    above the paper after every 57 ms M5 clearance pulse, with no drag or stray
    contact across hundreds of M3/M5 cycles. That satisfies T-01H's behavioral
    criterion and clears the 30-cycle requirement. The measured pen-tip gap and a
    force trace with F_contact_on/F_release_off remain the only formal items, and
    PEN_CLEAR_VALID stays false until then.
2026-09-25 Record the measured 1.75 mm pen-tip clearance
    The operator measured the pen-tip gap after M5 at approximately 1.75 mm,
    which clears the paper with margin and sits short of the home switch. This is
    the gap measurement T-01H required; the remaining formal item is a force trace
    with F_contact_on / F_release_off and the release debounce.
2026-09-25 Accept T-01H and recover from CS1238 implausible bursts
    T-01H is accepted: the 57 ms clearance was measured at about 1.75 mm of pen-tip
    gap with contact at ~40-47 g and release clearing to ~0 g across production
    prints and a four-cycle bench capture. PEN_CLEAR_VALID is flipped true, enabling
    the clear-ready status the GP27 handshake will consume (the handshake flag
    itself stays gated).
    Also extend the bounded auto-recovery to the CS1238 implausible-reading burst:
    reset the 16-sample streak, lift through the timed M5 clearance, and re-seek,
    capped by HARD_LIMIT_RECOVERY_MAX, instead of latching FAULT and dragging the
    pen. The dead-sensor read-timeout path still latches. recoveries= now repor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
    [pressure_controller.cpp, pressure_controller.h, pro_micro_rp2350_toolhead.ino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]
2026-09-25 Enable the GP27 normal-print status
    Flip GP27_NORMAL_STATUS_ENABLED true so the toolhead asserts GP27 with its
    contact-ready (M3) and clear-ready (M5) status while the magnetic protocol is
    disarmed. Mark F-08 passed on the strength of the P113 runs and move F-05A to
    in-progress. The flag alone does not change generated programs until P115.macro
    is installed and the converter checkbox is ticked.
    Compile-verified for rp2040:rp2040:sparkfun_promicrorp2350.
    [toolhead_config.h]
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2026-09-25 Default the GP27 handshake on
    toolhead_status_handshake now defaults to true, so the converter emits G65 P115
    after each M3/M5 instead of fixed G4 dwells without an extra step. The 24
    converter tests pass; two M-06 pen-free tests were updated to opt out
    explicitly. Unchecking the box still falls back to fixed dwells.
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2026-09-25 Guarantee a GP27 inactive interval on pen-command transitions
    The normal-print status asserts GP27 in both stable states
    (contact-ready and clear-ready), so the only inactive window was the
    physical seek/lift. When a transition completed instantly (an M5 from
    the GP2 lift switch), GP27 stayed asserted and P115 Q1 timed out its
    stale-state release phase with error 39, aborting the print.
    magnetic_homing.cpp now reads GP29 on core 1 to detect the M3/M5 edge
    and holds the GP27 output low for GP27_TRANSITION_LOW_MS (50 ms) before
    reasserting ready status.
    [magnetic_homing.cpp, toolhead_config.h]
2026-09-25 Widen the force-hold band to 30-60 g
    Fast prints let friction spike past the ±10 g band top and trigger a
    retract-only correction, lifting the pen off the page. Widen the
    target-ready band to ±15 g (30-60 g) and move the urgent relief trigger
    to 20 g above target, keeping 5 g of relief/stop hysteresis above the
    new band top.
    [toolhead_config.h]
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2026-09-26 Cap the drawable radius at the gantry's reach
    The bed rotates freely, so the safe drawable area is a circle whose radius is
    the gantry's tightest reach from the bed center (191.4 mm), not the full bed
    rim. Add a machine_reach_radius_mm setting and clip artwork at
    min(bed radius - margin, reach) so emitted coordinates stay inside the
    controller's X/Y envelope and cannot trip Alarm:2 soft limit.
    [gcode.py]
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2026-09-27 Chain line-family infill passes instead of lifting between them
    line_region_contours already emits consecutive hatch rows head-to-tail, reversing every other row for exactly that reason, but bridge_motion only let the pen stay down for concentric, triangular, diamonds and hexagonal. Every linear, crosshatch, diagonal, diagonal_crosshatch and cubic pass therefore paid its own pen cycle.
    Measured on a 40x40 mm filled square at 0.3 mm spacing: 183 passes, 184 pen cycles, 0 bridges, and a 0.424 mm connector between passes - narrower than the pen tip it refused to draw. Drawn length was already optimal at 5,256 mm against an ideal area/spacing of 5,333 mm, so the entire loss was pen cycles.
    The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
    [gcode.py]
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2026-09-27 Drag the artwork on the bed to place it
    plan_program centres the artwork's bounding box on the registered bed centre, which is not its visual centre for artwork with stray marks or an asymmetric outline; the F15 cutaway lands visibly down and left of centre for that reason, with no way to correct it.
    New signed settings artwork_offset_x_mm and artwork_offset_y_mm place the artwork centre at that offset from the bed centre. The reachable disc is fixed on the bed, so the clip is expressed in artwork coordinates about source_center - offset and the placement is applied when the contours move into the bed frame; with (0,0) nothing changes.
    In the preview the vertex shader takes a shift uniform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
    [gcode.py]
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2026-09-27 Parameterize the P115 handshake bounds and add a warn-only mode
    The fatal error-39 guard aborted healthy programs: the first M3 seeks from the GP2 lift-home switch and is measured at about 7 s against a fixed 5.00 s completion bound, and any genuine miss cost the whole sheet.
    P115 now snapshots its G65 arguments and accepts B (completion), C (release), D (poll), A (fallback dwell) and W1 (warn-only), defaulting to the commissioned values, plus a Q7 measure-only mode. The converter derives the first-down B bound from pen_down_first_ms and emits the fixed-dwell equivalent as A when warn-only is enabled. The strict error-39 paths remain the default.
    Verified: python tools\validate_homing_macr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
    [gcode.py]
2026-09-27 Add lift-and-continue recover mode to the P115 handshake
    On a normal M3/M5 handshake timeout the P115 macro now warns, issues M5
    to lift the pen to the fail-safe state, dwells for the pen-up clearance,
    and returns without error 39 so a long print continues at the next command
    instead of aborting. The end-of-print full-retract wait stays warn-only
    (W1, dwell without lift) because the Aux0/GP28 arm drives that retract.
    Adds the W2 recover flag to P115.macro, renames the converter setting to
    toolhead_handshake_recover, wires the Qt checkbox, and updates the
    validator, tests, and interface/ADR/current-state documentation.
    [gcode.py]
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2026-09-29 Hold the toolhead contact-ready level through hold corrections
    The F-05A dry-contact check showed GP27/PRB toggling in HOLD_FORCE while
    an M3-held pen sat stationary, so the pen-transition level P115 Q1 polls
    was not steady in the one state it must hold.
    STATUS_CONTACT_READY asserted after three filtered CS1238 conversions
    (about 4.7 ms) but released on a single out-of-band conversion, while the
    hold loop that corrects an excursion moves on a 250 ms cadence. Release is
    now hysteretic: an established ready level survives any excursion inside
    the 20 g urgent-relief bound and drops only after the force stays beyond
    it for CONTACT_READY_LOST_MS (500 ms). The assert side, state changes,
    fault pa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
    [pressure_controller.cpp, pressure_controller.h, toolhead_config.h]
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2026-09-29 Lower the pen force target to 38 g with a +/-10 g band
    TARGET_FORCE_RAW_DELTA and CONTACT_RAW_DELTA drop from 226,745 to 191,473 raw (45 -> 38 g at the E-09C 5,038.77 raw/g scale) and CONTACT_READY_TOLERANCE_RAW drops from 75,582 to 50,388 raw (+/-15 -> +/-10 g), giving a 28-48 g hold band. The 75 g hard limit and the 20 g urgent-relief offset are unchanged, so relief now trips at 58 g.
    The same pass corrects force, pulse-width, and pulse-ratio values that had gone stale against the code in firmware/README.md, firmware/pen_pressure/README.md, CONTROL_STRATEGY.md, docs/integration/INTERFACES.md, and docs/testing/TEST_PLAN.md (T-02/T-03), and replaces the retired two-touch seek description.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
    [pressure_controller.cpp, toolhead_config.h]
2026-09-30 Revert the pen force target to 45 g with a +/-15 g band
    Restores TARGET_FORCE_RAW_DELTA and CONTACT_RAW_DELTA to 226,745 raw (45 g) and CONTACT_READY_TOLERANCE_RAW to 75,582 raw (+/-15 g, a 30-60 g band) after the 38 g / +/-10 g setting from RPSW-20260929-004 was rejected by a print run. The 75 g hard limit is unchanged, so the urgent-relief trigger returns to 65 g.
    Keeps the 10 ms coarse-pulse width, 2:1 fine-pulse credit, and 75 g hard-limit corrections from RPSW-20260929-004 because they were documentation defects against the installed code. RPSW-20260929-004 is marked superseded; the revert is recorded as RPSW-20260929-005 and in the engineering log, including the three rejections of a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
    [toolhead_config.h]
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2026-09-30 Widen the 40 g pen-force band back to +/-15 g
    CONTACT_READY_TOLERANCE_RAW goes from 50,388 back to 75,582 raw, so the 40 g target holds in a 25-55 g band instead of 30-50 g. The target constants (201,551 raw), the 75 g hard limit and the 20 g relief offset are unchanged, so urgent relief still trips at 60 g - now exactly 5 g beyond the band top and 15 g below the hard limit.
    The +/-10 g band was widened to +/-15 g on 2026-09-25 after high-speed friction lifted the pen and a 2026-09-29 +/-10 g trial was rejected, so the lighter 40 g target is kept with the tolerance the mechanism is known to need. The 40 g target stands from RPSW-20260930-001; this note supersedes only its band.
    Verified by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
    [toolhead_config.h]
2026-09-30 Keep pen-down bridging off by default and tag generated fill trails
    The 2026-09-30 mandala print drew pen-down connectors across blank paper: mom.gcode carried 1,687 keep-down bridges in 367 chains, while the pre-fit generation had none. The 2026-09-24 rule was enforced as 'both contours are open', which cannot separate a fill trail from a line-art artwork's own open strokes, and the 0.964 fit rescale pushed those stroke gaps under the 0.85*spacing guard.
    Fill output now carries a FillTrail marker that survives element transforms, Y flip, scaling, pen-width compensation, bed clipping, plan placement, filtering and path reversal. bridge_motion requires the new keep_down_bridges setting (defa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
    [gcode.py, kinematics.py]
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2026-09-30 Theta drift: record the ratio in the G-code, ship a calibration plot
    Checked the report that the 12.03324 ratio change did not work: the ratio is
    applied by every A-axis calculation and the plotted file postdates the commit,
    so the change is in effect. The ambiguity was that a saved program did not say
    which ratio produced it, and a wrong ratio looks the same as backlash.
    - contours_to_gcode now writes the bed ratio, theta offset, feeds and tolerance
    into the preamble, so every program is self-documenting.
    - New tools/make_theta_calibration.py writes
    samples/gcode/theta-calibration.gcode through the production planner: eight
    radial ticks, one circle (one bed revolution) and a two-turn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
    [gcode.py]
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2026-10-01 Theta: re-register the bed each contour to keep the commanded A small
    The drift is worse where ioSender's A DRO is high and fine near A = 0 - the
    signature of an A-axis scale error, where a feature's positional error grows
    with its commanded angle. Monotonic-theta ordering deliberately accumulates
    rotation to avoid reversals, which is expensive on a real A axis.
    - _reregister_thetas() in gcode.py shifts each contour's bed angles by
    -360 * round(first_theta / 360); plan_program applies it before storing the
    plan so preview, estimate and file agree, and previous_theta becomes the
    re-registered value so the travel into the next contour carries the
    correction.
    - New theta_wrap setting (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
    [gcode.py]
2026-10-01 Kaleidoscope: report the tolerance budget; the centre wobble was that setting
    The plot from kaleidoscope1.gcode wobbled in the centre and the inner wave
    band, in the same places as before. It is not drift: the session's saved
    settings show tolerance 1.0 mm, four times the 0.25 mm default, and tolerance
    is the budget for how far the commanded path may sit from the intended bed
    line. It binds hardest where the bed rotates most per millimetre - tight inner
    curves and the inner sweep of the wave band.
    - Reproduced the design from the saved session (seed 83382, intricacy 10, 4
    divisions, no motifs) and measured the commanded path against the intended
    lines: at 1.0 mm the worst deviation is 0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
    [gcode.py]
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2026-10-01 Theta: stop asking the bed for motion it cannot follow
    Reconstructing ben.gcode into bed coordinates showed the file itself is even -
    rows exactly 2.000 mm apart, no crossings - while the commands are not
    executable: 64 drawing moves rotate the bed more than 60 motor deg each (up to
    561 motor deg, 46.6 bed deg, in one move at r=0.35-9.1 mm), drawing moves demand
    up to 1333 motor deg/s (111 bed deg/s, the assumed 80,000 motor deg/min cap),
    and every theta_wrap re-registration unwinds a whole revolution as a G0 rapid.
    A lagging bed bends the stroke being drawn and rotates everything after it:
    the fan around the bed centre in the print, and the rows drifting into their
    neighbours before it.
    -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
    [gcode.py, kinematics.py]
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2026-10-01 Max bed step: setting, hard limit, default 10 deg
    The operator saw defects at turns under the old 15 deg cap and asked for 10.
    Two problems surfaced:
    - the cap was only a cost preference - when the rotating option stayed cheaper,
    the planner still took it, so the documented guarantee was not enforced. It is
    now a hard limit: exceeding it parks the bed, which can always trace an in-disc
    move in X and Y.
    - it was a module constant. It is now 'Max bed step deg' in the Theta kinematics
    group (default 10, 0 allowed), and the main app's geometry cache key includes
    it.
    Measured on a 461-contour mandala, largest drawing step 14.62 / 9.92 / 5.00 deg
    at caps 15 / 10 / 5, with total bed rot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
    [kinematics.py]
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2026-10-01 Record the assumed A limits in the G-code preamble
    The converter and the controller have to agree on the A limits, and nothing in a
    saved file said what the planner assumed. After the 2026-10-01 settings session
    $113 was at 8000 while the converter still assumed 20000: the controller clips
    those moves so the path stays correct, but the feeds are unachievable as written
    and the time estimate is optimistic - and none of that is visible in the file.
    The preamble now carries
    '(A limits assumed 20000 motor deg/min, 3000 motor deg/s^2)', which can be
    compared with $$ at a glance. Preamble assertion updated.
    [gcode.py]
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2026-10-02 Raise the M5 clearance pulse to 70 ms and re-open its verification
    [pressure_controller.cpp, toolhead_config.h]
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
